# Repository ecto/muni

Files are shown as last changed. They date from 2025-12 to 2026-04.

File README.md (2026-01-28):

<picture>
  <source media="(prefers-color-scheme: dark)" srcset="web/public/images/muni-logo-dark.svg">
  <source media="(prefers-color-scheme: light)" srcset="web/public/images/muni-logo-light.svg">
  muni
</picture>

Open-source municipal robotics. Autonomous utility vehicles for public works, starting with sidewalk snow removal.

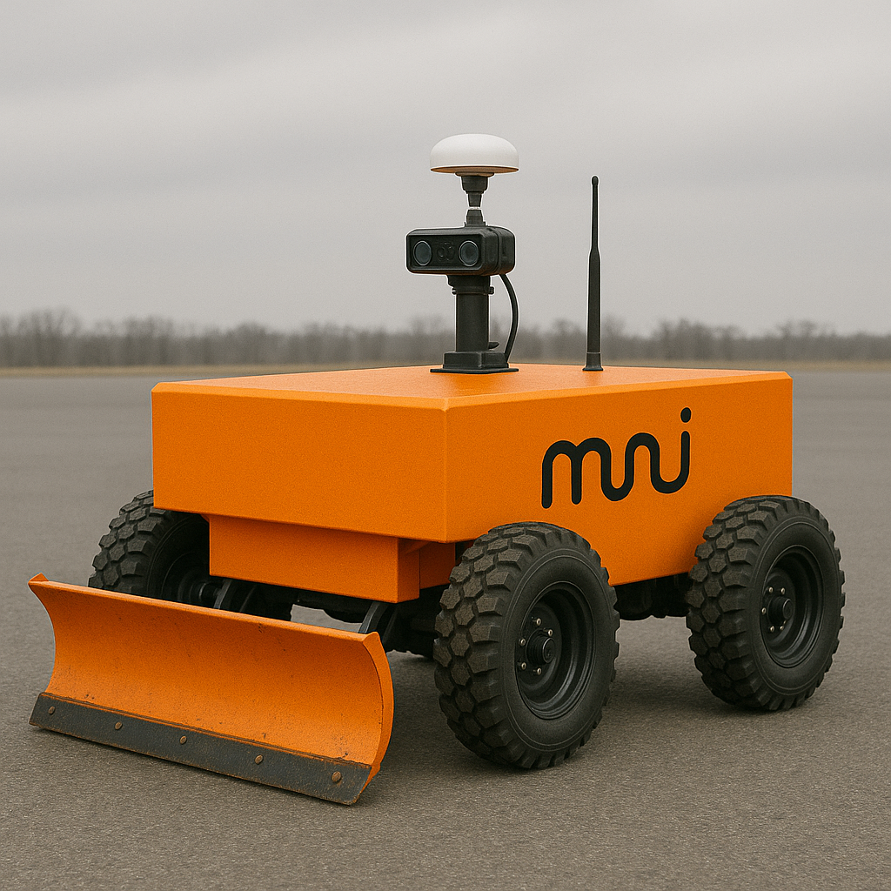
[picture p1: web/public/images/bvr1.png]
BVR rover with plow attachment


## Repository

```
muni/
├── bvr/              # Base Vectoring Rover (first morphology)
│   ├── firmware/     # Onboard software (Jetson Orin NX, Rust)
│   ├── cad/          # Mechanical design
│   ├── electrical/   # Schematics, PCBs
│   └── docs/         # BVR-specific documentation
├── depot/            # Base station (fleet ops, teleop, metrics)
├── mcu/              # Embedded firmware (RP2350, ESP32-S3)
├── paper/            # Technical documents (Typst)
└── web/              # Website
```

## Architecture

```
┌─────────────────────────────────────────────────────────────────────────────┐
│ Depot (Base Station)                                                        │
│                                                                             │
│   Console (:80)     Grafana (:3000)     InfluxDB        SFTP (:2222)       │
│   Fleet ops         Dashboards          Metrics DB      Session storage    │
│   Teleop UI         Alerts              Time series     Recording sync     │
└───────────────────────────────────┬─────────────────────────────────────────┘
                                    │
                        UDP metrics │ WebSocket teleop
                        SFTP sync   │ RTK corrections
                                    │
┌───────────────────────────────────┴─────────────────────────────────────────┐
│ BVR Rover                                                                   │
│                                                                             │
│   ┌─────────────────────────────────────────────────────────────────────┐  │
│   │ Jetson Orin NX                                                      │  │
│   │                                                                     │  │
│   │   bvrd (main daemon)                                                │  │
│   │   ├── teleop     Commands, telemetry, video streaming              │  │
│   │   ├── control    Differential drive mixer, rate limiting           │  │
│   │   ├── state      Mode management, safety interlocks                │  │
│   │   ├── gps        RTK positioning                                   │  │
│   │   └── recording  Session capture to .rrd files                     │  │
│   └───────────────────────────────┬─────────────────────────────────────┘  │
│                                   │ CAN bus                                 │
│       ┌───────────┬───────────────┼───────────────┬───────────────┐        │
│       │           │               │               │               │        │
│   ┌───┴───┐   ┌───┴───┐       ┌───┴───┐       ┌───┴───┐       ┌───┴───┐   │
│   │ VESC  │   │ VESC  │       │ VESC  │       │ VESC  │       │  MCU  │   │
│   │  FL   │   │  FR   │       │  RL   │       │  RR   │       │ LEDs  │   │
│   └───────┘   └───────┘       └───────┘       └───────┘       └───────┘   │
└─────────────────────────────────────────────────────────────────────────────┘
```

## Quick Start

### Base Station

```bash
cd depot
docker compose up -d
```

Console at http://localhost. See [depot/README.md](depot/README.md).

### BVR Firmware

```bash
cargo install --path bvr/firmware/bins/cli
muni deploy rover <rover-hostname>
```

See [bvr/firmware/README.md](bvr/firmware/README.md).

### MCU Firmware

```bash
cd mcu
cargo build --release -p mcu-rp2350
picotool load target/thumbv8m.main-none-eabihf/release/mcu-rp2350 -t elf -f
```

See [mcu/README.md](mcu/README.md).

## Documentation

| Topic | Link |
| --- | --- |
| System architecture | [bvr/docs/architecture.md](bvr/docs/architecture.md) |
| Hardware BOM | [docs/hardware/bom.md](docs/hardware/bom.md) |
| RTK GPS setup | [docs/hardware/rtk.md](docs/hardware/rtk.md) |
| Teleop system | [bvr/docs/teleop.md](bvr/docs/teleop.md) |
| Design language | [docs/design-language.md](docs/design-language.md) |

## License

MIT

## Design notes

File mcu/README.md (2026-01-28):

# MCU Firmware

Embedded firmware for CAN-connected microcontrollers on the rover.

## Architecture

```
mcu/
├── crates/
│   ├── mcu-core/          # Shared: CAN protocol, watchdog, heartbeat
│   └── mcu-leds/          # Driver: LED animations and control
└── bins/
    ├── rp2350/            # Binary: Base rover LED controller (Pico 2 W)
    └── esp32s3/           # Binary: Attachment controller (ESP32-S3)
```

## Hardware

### LED Controller (mcu-rp2350)

- **MCU**: Raspberry Pi Pico 2 W (RP2350)
- **LEDs**: WS2811 12V addressable strip (ALITOVE RGB, 4 addressable units)
- **CAN**: MCP2515 via SPI (planned)

#### Pinout

| Pico 2 Pin | Function |
| --- | --- |
| GP0 | LED data out |
| GP16 | MCP2515 MISO (TBD) |
| GP17 | MCP2515 CS (TBD) |
| GP18 | MCP2515 SCK (TBD)  |
| GP19 | MCP2515 MOSI (TBD) |
| GP20 | MCP2515 INT (TBD)  |

#### LED Wiring (WS2811 12V Strip)

```
LED Strip          Pico 2 W
─────────          ────────
+12V (red)    -->  External 12V supply
GND (white)   -->  GND (shared with 12V supply)
DIN (green)   -->  GP0 (data output)
```

**Important**: The data wire (green) must connect to the **input** end of the strip (marked with arrow or "DIN"). Data flows in one direction only.

### Attachment Controller (mcu-esp32s3)

- **MCU**: Heltec WiFi LoRa 32 V3 (ESP32-S3FN8)
- **Display**: Onboard 0.96" 128x64 OLED (SSD1306, I2C)
- **CAN**: ESP32-S3 native TWAI controller (no external chip needed)

This is a generic attachment controller for CAN-connected tool attachments. The OLED display shows status, CAN statistics, and debug info.

#### Pinout (Heltec V3)

| GPIO | Function | Notes |
| ---- | --- | --- |
| 17 | OLED SDA | I2C data (fixed) |
| 18 | OLED SCL | I2C clock (fixed) |
| 21 | OLED RST | Display reset (fixed) |
| 36 | Vext | OLED/peripheral power ctrl  |
| 35 | LED | Onboard status LED |
| 0 | PRG Button | Boot/user button |
| 4 | TWAI RX | CAN receive (configurable)  |
| 5 | TWAI TX | CAN transmit (configurable) |

#### Features

- `oled` (default): Enable OLED display support

#### CAN Wiring

Connect a CAN transceiver (e.g., SN65HVD230 or MCP2551) to GPIO4 (RX) and GPIO5 (TX):

```
ESP32-S3         CAN Transceiver       CAN Bus
────────         ───────────────       ───────
GPIO4 (RX)  <--  RXD
GPIO5 (TX)  -->  TXD
3.3V        -->  VCC
GND         -->  GND
                 CANH            <-->  CAN_H
                 CANL            <-->  CAN_L
```

## CAN Protocol

### ID Ranges

| Range | Purpose |
| --- | --- |
| 0x0A00-0x0AFF | Tool attachments (uses discovery) |
| 0x0B00-0x0BFF | Base rover peripherals (fixed assignment) |

### LED Controller (0x0B00-0x0B01)

**Command (0x0B00, Jetson -> MCU):**

```
[0]: Mode (0x00=Off, 0x01=Solid, 0x02=Pulse, 0x03=Chase, 0x04=Flash, 0x10=StateLinked)
[1]: Red (0-255)
[2]: Green (0-255)
[3]: Blue (0-255)
[4]: Brightness (0-255)
[5-6]: Period (ms, little-endian, for animations)
[7]: Reserved
```

**Status (0x0B01, MCU -> Jetson):**

```
[0]: Status (0x00=OK, 0x01=Fault)
[1]: Uptime seconds (wraps at 255)
[2-7]: Reserved
```

## Building

### Prerequisites

```bash
# Install Rust target for RP2350
rustup target add thumbv8m.main-none-eabihf

# Install picotool (for flashing)
brew install picotool  # macOS
# or build from https://github.com/raspberrypi/picotool
```

### Build

```bash
cd mcu
cargo build --release -p mcu-rp2350
```

### Flash

1. **Enter BOOTSEL mode**: Hold BOOTSEL button while plugging in USB
2. **Flash with picotool**:

```bash
picotool load target/thumbv8m.main-none-eabihf/release/mcu-rp2350 -t elf -f
picotool reboot
```

**Note**: Do NOT use `elf2uf2-rs` for RP2350 - it generates the wrong UF2 family ID (RP2040 instead of RP2350). Use `picotool` which correctly identifies the target.

## Debugging

Uses `defmt` for logging. With a debug probe (Picoprobe, etc.):

```bash
probe-rs run --chip RP235x target/thumbv8m.main-none-eabihf/release/mcu-rp2350
```

Without a debug probe, add USB serial logging (see embassy-usb-logger).

## RP2350 / Pico 2 W Notes

### Key Differences from RP2040

1. **Different UF2 family ID**: RP2350 uses `rp2350-arm-s` (0xe48bff59), not RP2040's 0xe48bff56
2. **Boot2 required**: Must enable `boot2-w25q080` feature in embassy-rp for the flash bootloader
3. **Memory layout**: Requires special linker sections for boot blocks (`.start_block`, `.end_block`)
4. **Onboard LED**: On Pico 2 W, the LED is controlled via CYW43 WiFi chip (not GPIO25)

### Required Embassy Features

```toml
embassy-rp = { version = "0.9", features = [
    "rp235xa",              # RP2350 variant
    "time-driver",          # Async timers
    "boot2-w25q080",        # Flash bootloader (REQUIRED)
    "critical-section-impl", # Critical section implementation
    "binary-info",          # Picotool metadata
] }
```

### Required Linker Script Sections

The `memory.x` must include boot block sections for RP2350:

```ld
SECTIONS {
    .start_block : ALIGN(4) {
        __start_block_addr = .;
        KEEP(*(.start_block));
        KEEP(*(.boot_info));
    } > FLASH
} INSERT AFTER .vector_table;

_stext = ADDR(.start_block) + SIZEOF(.start_block);

SECTIONS {
    .bi_entries : ALIGN(4) {
        __bi_entries_start = .;
        KEEP(*(.bi_entries));
        . = ALIGN(4);
        __bi_entries_end = .;
    } > FLASH
} INSERT AFTER .text;

SECTIONS {
    .end_block : ALIGN(4) {
        __end_block_addr = .;
        KEEP(*(.end_block));
    } > FLASH
} INSERT AFTER .uninit;
```

### Build.rs Requirements

```rust
// Required linker args for RP2350
println!("cargo:rustc-link-arg-bins=--nmagic");
println!("cargo:rustc-link-arg-bins=-Tlink.x");
println!("cargo:rustc-link-arg-bins=-Tdefmt.x");
```

### Troubleshooting

**Firmware doesn't run after flashing:**

- Verify UF2 family ID is `rp2350-arm-s` (check with `xxd file.uf2 | head`)
- Use `picotool` instead of `elf2uf2-rs`
- Check `picotool info -a` for boot diagnostics

**Picotool shows "Program Information: none":**

- Device is in BOOTSEL mode, not running application
- Check that boot2 feature is enabled
- Verify memory.x has correct boot block sections

**LEDs not working:**

- Verify data wire goes to DIN (input) end of strip
- Check WS2811 vs WS2812 timing (WS2811 uses 400kHz, WS2812 uses 800kHz)
- Try different color order (GRB vs RGB) - use `Grb` type in PioWs2812
- Confirm LED count matches addressable units (WS2811 12V has 3 LEDs per IC)

## LED Modes

| Mode  | Color  | Effect | Use Case |
| ----- | --- | --- | --- |
| Off | - | - | Disabled |
| Solid | Green  | Constant | Idle |
| Pulse | Blue | Breathing | Teleop active |
| Pulse | Cyan | Breathing | Autonomous |
| Flash | Red | Strobe 200ms | E-Stop |
| Flash | Orange | Strobe 500ms | Fault |

## ESP32-S3 / Heltec LoRa 32 V3 Notes

### Prerequisites

```bash
# Install espup (ESP32 Rust toolchain manager)
cargo install espup
espup install

# Source the environment (add to shell profile for persistence)
source ~/export-esp.sh

# Install espflash for flashing
cargo install espflash
```

### Build

```bash
cd mcu/bins/esp32s3
cargo build --release
```

### Flash

```bash
# Flash and open serial monitor
espflash flash --monitor target/xtensa-esp32s3-none-elf/release/mcu-esp32s3

# Or just flash
espflash flash target/xtensa-esp32s3-none-elf/release/mcu-esp32s3
```

The board will automatically reset and start running after flashing.

### Debugging

Serial output uses `defmt` via `esp-println`. The `--monitor` flag with espflash shows logs:

```bash
espflash flash --monitor target/xtensa-esp32s3-none-elf/release/mcu-esp32s3
```

### Troubleshooting

**"Permission denied" on /dev/ttyUSB0 or /dev/ttyACM0:**

```bash
sudo usermod -a -G dialout $USER
# Log out and back in
```

**OLED not displaying:**

- Check Vext is enabled (GPIO36 low)
- Verify OLED reset sequence (GPIO21 low then high)
- Confirm I2C address is 0x3C

**CAN not working:**

- Verify CAN transceiver is connected and powered
- Check termination resistors (120Ω at each end of bus)
- Confirm baud rate matches other nodes (500kbps default)

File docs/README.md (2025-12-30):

# Muni Platform Documentation

Platform-level documentation for the Muni robotics system.

## Contents

- Fleet management and deployment
- Depot configuration and operations
- Cross-morphology standards

## Hardware

- [Bill of Materials](hardware/bom.md) — Complete parts list and costs
- [Depot Rack](hardware/depot.md) — Base station 10" rack setup
- [Rover Rack](hardware/rover-rack.md) — Rover electronics enclosure
- [RTK GPS](hardware/rtk.md) — Centimeter-accurate positioning
- [Motors](hardware/motors.md) — Hub motor specifications
- [Networking](hardware/networking.md) — LTE and local connectivity
- [Firmware](hardware/firmware.md) — Flashing bvrd and attachments

## Morphology-Specific Docs

For hardware and firmware documentation specific to each robot type, see:

- [BVR Documentation](../bvr/docs/) — Base Vectoring Rover

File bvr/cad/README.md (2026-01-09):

# BVR CAD

Parametric CAD system for BVR rover parts, written in Rust using [manifold-rs](https://github.com/WilstonOreo/manifold-rs).

## Structure

```
cad/
├── src/
│   ├── lib.rs          # Core Part abstraction
│   ├── step.rs         # STEP export (optional, requires OpenCASCADE)
│   ├── parts/          # Part definitions
│   │   ├── motor_mount.rs      # Custom: L-bracket motor mounts
│   │   ├── electronics_plate.rs # Custom: Electronics mounting plate
│   │   ├── sensor_mount.rs     # Custom: Sensor mast bracket
│   │   ├── wheel_spacer.rs     # Custom: Wheel spacers
│   │   ├── frame.rs            # Frame: 2020 extrusion, brackets
│   │   ├── hub_motor.rs        # Reference: Hub motors
│   │   ├── sensors.rs          # Reference: LiDAR, cameras, GPS
│   │   ├── electronics.rs      # Reference: VESCs, Jetson, DC-DC
│   │   ├── battery.rs          # Reference: Battery packs
│   │   └── assembly.rs         # Complete BVR1 assembly
│   └── bin/
│       └── generate_all.rs
├── exports/            # Generated STL files (29 parts)
└── viewer.html         # 3D viewer (Three.js)
```

## Quick Start

```bash
# Build the CAD library
cargo build

# Generate all parts (31 STL files)
cargo run --bin generate-all

# Run tests (51 tests)
cargo test

# View parts in browser
open viewer.html
```

## Part Categories

### Custom Fabricated Parts

These are parts designed for manufacturing (3D printing, laser cutting):

| Part | Description | File |
|---|---|---|
| Motor Mount | L-bracket for hub motors | `motor_mount_8in.stl` |
| Electronics Plate | Jetson + 4x VESC mounting | `electronics_plate.stl` |
| Sensor Mount | 1" tube clamp for mast | `sensor_mount.stl` |
| Wheel Spacer | Hub motor axle spacer | `wheel_spacer_8in.stl` |
| Battery Tray | Custom battery enclosure | `battery_tray.stl` |

### Reference Parts (Visualization)

Simplified models of off-the-shelf components for assembly visualization:

| Part | Description | File |
|---|---|---|
| Hub Motor 8" | 48V hub motor with wheel | `ref_hub_motor_8in.stl` |
| Hoverboard Motor | 6.5" BVR0-style motor | `ref_hub_motor_hoverboard.stl` |
| LiDAR Mid-360 | Livox Mid-360 sensor | `ref_lidar_mid360.stl` |
| Camera | Insta360 X4 | `ref_camera_insta360.stl` |
| GPS Antenna | RTK antenna | `ref_gps_antenna.stl` |
| VESC 6 | Motor controller | `ref_vesc_6.stl` |
| Jetson | reComputer carrier | `ref_jetson_recomputer.stl` |
| DC-DC | 48V to 12V converter | `ref_dcdc.stl` |
| E-Stop | Mushroom button | `ref_estop.stl` |
| Downtube Battery | BVR0 e-bike battery | `ref_battery_downtube.stl` |
| Custom Battery | BVR1 13S4P pack | `ref_battery_custom.stl` |

### Frame Components

2020 aluminum extrusion system:

| Part | Description | File |
|---|---|---|
| 2020 Extrusion | Standard profiles | `extrusion_2020_*.stl` |
| Corner Bracket | 90° joining bracket | `corner_bracket.stl` |
| T-Nut | M5 sliding nut | `tnut_m5.stl` |
| BVR1 Frame | Complete chassis | `bvr1_frame.stl` |

### Complete Assemblies

| Assembly | Description | File |
|---|---|---|
| BVR0 Full | Prototype with hoverboard motors, downtube battery | `bvr0_assembly.stl` |
| BVR0 Simple | Simplified BVR0 for fast rendering | `bvr0_assembly_simple.stl` |
| BVR1 Full | Production with 8" motors, custom battery | `bvr1_assembly.stl` |
| BVR1 Simple | Simplified BVR1 for fast rendering | `bvr1_assembly_simple.stl` |

## Usage Examples

### Frame

```rust
use bvr_cad::parts::{Extrusion2020, CornerBracket, BVR1Frame};

// Single extrusion
let rail = Extrusion2020::new(500.0).generate();
rail.write_stl("rail.stl")?;

// Complete BVR1 frame assembly
let frame = BVR1Frame::default_bvr1().generate();
frame.write_stl("bvr1_frame.stl")?;
```

### Motor Mount

```rust
use bvr_cad::parts::MotorMount;

let mount = MotorMount::hub_motor_8in();
mount.generate().write_stl("motor_mount.stl")?;
mount.generate_flat_plate().write_stl("plate.stl")?; // For laser cutting
```

### Complete Assembly

```rust
use bvr_cad::parts::{BVR0Assembly, BVR1Assembly};

// BVR0: Prototype with hoverboard motors, downtube battery
let bvr0 = BVR0Assembly::default_bvr0();
bvr0.generate().write_stl("bvr0_complete.stl")?;

// BVR1: Production with 8" motors, custom battery
let bvr1 = BVR1Assembly::default_bvr1();
bvr1.generate().write_stl("bvr1_complete.stl")?;
```

### Custom Primitives

```rust
use bvr_cad::{Part, centered_cube, centered_cylinder, bolt_pattern};

// Primitives
let plate = centered_cube("plate", 100.0, 100.0, 6.0);
let hole = centered_cylinder("hole", 5.0, 10.0, 32);

// Boolean operations
let result = plate.difference(&hole);

// Transformations
let moved = result.translate(10.0, 0.0, 0.0);
let rotated = moved.rotate(0.0, 0.0, 45.0);

// Export
result.write_stl("output.stl")?;
```

## Manufacturing

### Laser Cutting (SendCutSend)
- Use `generate_flat_plate()` methods for 2D profiles
- Export STL, convert to DXF using FreeCAD/Blender

### 3D Printing
- Use `generate()` for full 3D parts
- STL files ready for slicing

### STEP Export (for Shapr3D, Fusion 360)
Requires OpenCASCADE (optional feature):

```bash
# Install dependencies
brew install cmake opencascade  # macOS
sudo apt install cmake libocct-dev  # Ubuntu

# Build with STEP support
cargo build --features step
```

## Dependencies

- `manifold-rs` - CSG geometry kernel (requires cmake, ninja)
- `nalgebra` - Linear algebra
- `opencascade` (optional) - STEP export (requires OCCT)

## Build Requirements

```bash
# macOS
brew install cmake ninja

# Ubuntu/Debian
sudo apt install cmake ninja-build build-essential
```

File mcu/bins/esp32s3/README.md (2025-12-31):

# ESP32-S3 MCU Firmware

Generic attachment controller firmware for ESP32-S3 based boards (Heltec LoRa 32 V3, etc.).

## Features

- **OLED Display**: 128x64 SSD1306 with animated UI
  - Splash screen with Muni branding
  - Status indicator with pulsing animation
  - State display (IDLE, RUNNING, ERROR)
  - Cycling info bar (activity, CAN health, device info)
- **Dual Protocol Serial Interface**:
  - Text commands for debugging
  - SLCAN (CAN-over-serial) for bvrd integration
- **Status LEDs** (feature: `status-bar`):
  - 5 GPIO LEDs: Red (error), Yellow (warn), Green (idle), Blue (running), White (heartbeat)
  - Configurable patterns per state
- **Addressable LED Driver** (feature: `addressable-leds`):
  - RMT-based for precise timing
  - WS2811 (400kHz) and WS2812/SK6812 (800kHz) support
  - RGB/GRB/BGR color order options
  - RGB cycle mode for testing

## Supported Hardware

- **Heltec WiFi LoRa 32 V3 / V3.2** (ESP32-S3FN8)
- Other ESP32-S3 boards with minor pin adjustments

### Heltec V3 Pinout

| GPIO | Function | Notes |
| ---- | --- | --- |
| 17 | OLED SDA | I2C data |
| 18 | OLED SCL | I2C clock |
| 21 | OLED RST | Display reset |
| 36 | Vext | OLED power control (LOW = on) |
| 35 | LED | Onboard status LED |
| 0 | PRG Button | Boot/user button |
| 4 | LED Strip Data | WS2811/WS2812 (needs level shifter for 12V strips) |
| 43 | UART TX | Serial output (CP2102) |
| 44 | UART RX | Serial input (CP2102) |

### Status Bar LEDs (feature: `status-bar`)

| GPIO | Color  | Meaning |
| ---- | --- | --- |
| 19 | Red | Error/fault |
| 20 | Yellow | Warning/attention |
| 26 | Green  | Idle/ok |
| 48 | Blue | Running/active |
| 47 | White  | Heartbeat |

Wire each LED: `GPIO → 330Ω resistor → LED anode (+) → LED cathode (-) → GND`

## Communication Protocols

The firmware supports two protocols over USB serial:

### 1. Text Commands (Human/Debug)

Connect via screen or any serial terminal at 115200 baud:

```bash
screen /dev/cu.usbserial-0001 115200
```

| Command | Description |
| --- | --- |
| `led r,g,b` | Set LED color (0-255 each) |
| `led off` | Turn off LEDs |
| `cycle` | Toggle RGB rainbow cycle mode  |
| `state idle` | Set display state to IDLE |
| `state running` | Set display state to RUNNING |
| `state error` | Set display state to ERROR |
| `rgb/grb/bgr` | Set LED color order |
| `ws2811/ws2812` | Set LED timing (400kHz/800kHz) |
| `help` | Show available commands |

Exit screen with `Ctrl+A` then `K` then `Y`.

### 2. SLCAN (CAN-over-Serial for bvrd)

The firmware implements SLCAN protocol for integration with bvrd. This allows unified CAN messaging whether using USB serial or hardware CAN.

**SLCAN Commands:**

| Command | Description |
| --- | --- |
| `O` | Open CAN channel (starts heartbeat) |
| `C` | Close CAN channel |
| `tIIILDD...` | Send standard frame (11-bit ID) |
| `TIIIIIIIILDD...` | Send extended frame (29-bit ID) |
| `V` | Query firmware version |
| `N` | Query serial number |

**Example:**

```bash
# Open channel
echo -ne "O\r" > /dev/ttyUSB0

# Query identity (ID 0x201, 0 data bytes)
echo -ne "t2010\r" > /dev/ttyUSB0

# Set LED to red (ID 0x203, cmd=0x10, r=255, g=0, b=0)
echo -ne "t20341000FF00\r" > /dev/ttyUSB0
```

## CAN Protocol (Message IDs)

Attachments use CAN IDs in the `0x200-0x2FF` range. Each attachment slot gets 16 IDs.

### Attachment Slot 0 (Base ID 0x200)

| ID | Dir | Name | Description |
| ----- | --- | --- | --- |
| 0x200 | A→H | Heartbeat | Periodic status (1Hz when channel open) |
| 0x201 | H→A | Identify  | Request attachment info |
| 0x202 | A→H | Identity  | Response with type/version/caps |
| 0x203 | H→A | Command | Control command |
| 0x204 | A→H | Ack | Command acknowledgment |
| 0x205 | A→H | Sensor | Sensor data broadcast |
| 0x206 | H→A | Config | Configuration update |
| 0x207 | A→H | Error | Error/fault report |

A = Attachment, H = Host (bvrd/Jetson)

### Heartbeat Frame (0x200)

Sent every ~1 second when SLCAN channel is open:

```
Byte 0: State (0=Idle, 1=Running, 2=Error, 3=Warning)
Byte 1: Uptime (seconds, low byte)
Byte 2: Uptime (seconds, high byte)
Byte 3: Flags (reserved)
```

### Identity Frame (0x202)

Response to Identify request:

```
Byte 0: Attachment type (0x02 = LedStrip)
Byte 1: Hardware revision
Byte 2: Software version major
Byte 3: Software version minor
Byte 4: Capabilities (0x01=LED, 0x02=Sensor, 0x04=Actuator)
```

### Command Frame (0x203)

| Cmd  | Name | Args |
| ---- | --- | --- |
| 0x00 | Nop | (none) |
| 0x01 | Enable | (none) |
| 0x02 | Disable | (none) |
| 0x03 | SetState  | arg0=state |
| 0x10 | SetLed | arg0=R, arg1=G, arg2=B |
| 0x11 | LedCycle  | arg0=0/1 (off/on) |
| 0x12 | LedTiming | arg0=0/1 (SK68/WS2811) |
| 0x13 | LedOrder  | arg0=0/1/2 (RGB/GRB/BGR) |

### Ack Frame (0x204)

```
Byte 0: Command that was acknowledged
Byte 1: Result (0x00=Ok, 0x01=UnknownCmd, 0x02=InvalidArgs)
```

## Full-Stack Integration

```
┌─────────────┐     WebSocket      ┌─────────────┐
│  Operator   │◄──────────────────►│   Depot     │
│    App      │                    │  (Cloud)    │
└─────────────┘                    └─────────────┘
                                          ▲
                                          │ gRPC/HTTP
                                          ▼
                                   ┌─────────────┐
                                   │    bvrd     │
                                   │  (Jetson)   │
                                   └─────────────┘
                                          ▲
                                          │ USB Serial (SLCAN)
                                          ▼
                                   ┌─────────────┐
                                   │ Attachment  │
                                   │   (ESP32)   │
                                   └─────────────┘
```

1. **Discovery**: bvrd detects USB device, sends `O` then `t2010` (Identify)
2. **Registration**: Attachment responds with Identity frame (0x202)
3. **Heartbeat**: Attachment sends periodic heartbeat (0x200)
4. **Control**: Operator sends command through Depot → bvrd → SLCAN → Attachment
5. **Status**: Attachment heartbeat flows back to Operator via Depot

## Prerequisites

```bash
# Install ESP32 Rust toolchain
cargo install espup
espup install

# Add to your shell profile (~/.zshrc or ~/.bashrc)
source ~/export-esp.sh

# Install espflash
cargo install espflash
```

## Building

```bash
cd mcu/bins/esp32s3
source ~/export-esp.sh
cargo build --release
```

## Flashing

**Important**: Use the included `bootloader.bin` to avoid chip revision compatibility issues.

```bash
espflash flash \
    --ignore-app-descriptor \
    --partition-table partitions.csv \
    --bootloader bootloader.bin \
    --min-chip-rev 0.0 \
    target/xtensa-esp32s3-none-elf/release/mcu-esp32s3
```

To monitor serial output:

```bash
espflash monitor
```

Press `CTRL+R` to reset, `CTRL+C` to exit.

## WS2811 LED Strip Setup

The ESP32 outputs 3.3V logic, but 12V WS2811 strips require 5V logic levels.

### Required Hardware

**Level Shifter**: Use a bidirectional logic level converter (3.3V to 5V):

- 4-channel I2C Logic Level Converter module (recommended)
- 74HCT125
- SN74AHCT125N
- TXB0104

### Wiring with Level Shifter

```
ESP32 (3.3V side)          Level Shifter          LED Strip (5V side)
─────────────────          ─────────────          ──────────────────
3.3V  ──────────────────── LV
GND   ──────────────────── GND ─────────────────── GND
GPIO4 ──────────────────── LV1 ──── HV1 ────────── DIN
                           HV ──────────────────── 5V (from LED power)
```

| From | To |
| --- | --- |
| ESP32 3.3V | LV pin |
| ESP32 GND | GND pin (either side) |
| ESP32 GPIO4 | LV1 |
| 5V power supply | HV pin |
| HV1 | LED strip DIN |

### Why Level Shifting is Required

- WS2811 data input threshold: ~0.7 \* VDD = 3.5V (for 5V power)
- ESP32 GPIO output: 3.3V
- 3.3V < 3.5V = unreliable detection

Without a level shifter, only the first LED may respond, and colors will be incorrect.

## Critical Configuration

### .cargo/config.toml

The linker script is **required** for proper linking:

```toml
[target.xtensa-esp32s3-none-elf]
runner = "espflash flash --monitor"
rustflags = [
  "-C", "link-arg=-Wl,-Tlinkall.x",  # REQUIRED: Links esp-hal runtime
  "-C", "link-arg=-nostartfiles",
]

[build]
target = "xtensa-esp32s3-none-elf"

[unstable]
build-std = ["alloc", "core"]
```

Without `-Tlinkall.x`, the binary will have entry point 0x0 and fail to boot.

### Bootloader Compatibility

ESP-IDF v5.5.x bootloaders have a strict "efuse block revision" check that fails on ESP32-S3 v0.2 chips. The error looks like:

```
E (95) boot_comm: Image requires efuse blk rev >= v20.50, but chip is v1.3
E (101) boot: Factory app partition is not bootable
```

**Solution**: Use the included `bootloader.bin` (ESP-IDF v5.1-beta1) which doesn't have this check.

To update the bootloader:

```bash
curl -sL "https://github.com/esp-rs/espflash/raw/v3.0.0/espflash/resources/bootloaders/esp32s3-bootloader.bin" -o bootloader.bin
```

## Entering Bootloader Mode

If the board is stuck or unresponsive:

1. **Unplug USB**
2. **Hold BOOT/PRG button**
3. **Plug in USB** (keep holding)
4. **Release after 2 seconds**

This forces download mode for flashing.

## Troubleshooting

### Binary is empty / entry point 0x0

- Check `.cargo/config.toml` has `-Wl,-Tlinkall.x`
- Verify `build-std = ["alloc", "core"]`
- Clean rebuild: `cargo clean && cargo build --release`

Verify with:

```bash
xtensa-esp32s3-elf-readelf -h target/xtensa-esp32s3-none-elf/release/mcu-esp32s3
# Entry point should be ~0x40378xxx, not 0x0
```

### "abort() was called" on boot

- Usually caused by missing linker script
- Check entry point as above

### "efuse blk rev" error

- Use older bootloader: `--bootloader bootloader.bin`
- ESP-IDF v5.5.x has incompatible checks for v0.2 chips

### OLED not displaying

- Vext must be LOW (GPIO36) to power display
- Reset sequence: GPIO21 LOW -> 50ms -> HIGH -> 50ms
- I2C address: 0x3C (some boards use 0x3D)
- Pins: SDA=GPIO17, SCL=GPIO18

### UART read blocking main loop

- Use `embedded_io::ReadReady` trait to check for data before reading
- `uart.read()` is blocking; always check `read_ready()` first

### Serial port not found

```bash
# Check if another process is using it
lsof /dev/cu.usbserial-*

# Kill conflicting processes
killall screen
```

### Permission denied (Linux)

```bash
sudo usermod -a -G dialout $USER
# Log out and back in
```

### LEDs not responding (WS2811)

- **Level shifter required**: 3.3V GPIO cannot reliably drive 5V WS2811
- Check wiring: GND must be shared between ESP32 and LED power supply
- Verify data pin is connected to strip INPUT (marked DIN or with arrow)
- Try different GPIO if issues persist

## Files

| File | Purpose |
| --- | --- |
| `bootloader.bin` | ESP-IDF v5.1-beta1 bootloader (compatible) |
| `partitions.csv` | Partition table (nvs, phy_init, factory) |
| `.cargo/config.toml`  | Cargo build configuration with linker args |
| `rust-toolchain.toml` | ESP Rust toolchain specification |

## Lessons Learned

1. **Linker script is mandatory**: Without `-Wl,-Tlinkall.x`, the esp-hal runtime isn't linked and the binary is empty.

2. **Bootloader version matters**: ESP-IDF v5.5.x introduced strict efuse block revision checks that reject valid binaries on older ESP32-S3 chips (v0.2).

3. **Vext controls OLED power**: The Heltec boards use GPIO36 (active low) to control power to the OLED and other peripherals. Must be set LOW before display works.

4. **OLED reset sequence is required**: GPIO21 must be toggled (low -> high) with delays for the SSD1306 to initialize properly.

5. **Use `core::mem::forget` for GPIO pins**: If GPIO pins go out of scope, they're reconfigured. Use `forget()` to keep them alive.

6. **UART read is blocking**: The `embedded_io::Read` trait's `read()` method blocks. Use `ReadReady::read_ready()` first to avoid blocking the main loop.

7. **WS2811 vs WS2812 timing**: WS2811 (often 12V strips) uses 400kHz timing, WS2812 (5V strips) uses 800kHz. The timing is completely different.

8. **Level shifting for LED strips**: 12V WS2811 strips need 5V logic. ESP32's 3.3V output is below the detection threshold. A bidirectional level shifter is required.

9. **heapless collections can panic**: Using `.collect()` on iterators with `heapless::Vec` will panic if the iterator has more elements than the Vec capacity. Use manual iteration instead.

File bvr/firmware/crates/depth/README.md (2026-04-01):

# depth — Camera-Based Perception

Monocular depth estimation, 3D back-projection, and visual odometry for
BVR rovers using commodity USB cameras instead of lidar.

## Architecture

```
3× Arducam IMX291 (120° FOV, USB 2.0)
        │
        ▼ raw RGB (640×480 @ 15fps)
┌─────────────────────────────────────────────────┐
│  depth crate                                    │
│                                                 │
│  1. DepthEstimator (ONNX)                       │
│     RGB → relative depth map (518×518)          │
│     Depth Anything V2/V3 Small, TensorRT on     │
│     Jetson Orin NX                              │
│                                                 │
│  2. estimate_metric_scale()                     │
│     Relative depth → metric depth using known   │
│     camera mount height as reference            │
│                                                 │
│  3. backproject_and_classify()                  │
│     Depth pixels → 3D points in rover frame     │
│     Classified as ground or obstacle by height  │
│                                                 │
│  4. VisualOdometry (2D ICP)                     │
│     Frame-to-frame ego-motion from ground-plane │
│     point alignment. Returns (dx, dy, dθ)       │
│     compatible with EKF prediction.             │
└──────────┬──────────────────────┬───────────────┘
           │                      │
           ▼                      ▼
     Costmap update         EKF prediction
     (obstacles →           (replaces wheel
      navigation)            odometry)
```

## Coordinate Frames

**Camera frame** (OpenCV): Z-forward, X-right, Y-down
**Rover frame** (ROS): X-forward, Y-left, Z-up

Base rotation (camera → rover, no mount):
```
rover_X =  cam_Z    (forward = depth)
rover_Y = -cam_X    (left = -right)
rover_Z = -cam_Y    (up = -down)
```

**Mount rotation convention**: `[roll, pitch, yaw]` Euler angles (intrinsic
ZYX via `nalgebra::from_euler_angles`) describing the rotation FROM rover
frame TO camera frame. Negative pitch = looking down.

Transform to rover frame: `R_mount.transpose() * R_cam_to_rover_base * p_cam + translation`

## Camera Mount Configuration

```toml
# config/bvr.toml — 3× cameras at 120° apart for ~360° coverage

[[camera.mounts]]
id = "left"
device_hint = "/dev/video0"
mount_position = [0.25, 0.12, 0.25]      # [forward, left, up] meters
mount_rotation = [0.0, -0.175, -2.094]    # [roll, pitch, yaw] radians
fov_h = 1.745   # ~100° horizontal
fov_v = 1.18    # ~68° vertical

[[camera.mounts]]
id = "center"
device_hint = "/dev/video2"
mount_position = [0.25, 0.0, 0.25]
mount_rotation = [0.0, -0.175, 0.0]       # forward-facing

[[camera.mounts]]
id = "right"
device_hint = "/dev/video4"
mount_position = [0.25, -0.12, 0.25]
mount_rotation = [0.0, -0.175, 2.094]     # yaw +120°
```

## Depth Perception Configuration

```toml
[depth]
enabled = true
model_path = "/var/lib/bvr/models/depth-anything-v2-small.onnx"
model_input_width = 518
model_input_height = 518
capture_width = 640
capture_height = 480
capture_fps = 15
max_depth = 8.0
min_depth = 0.3
ground_threshold = 0.10
stride = 4
visual_odometry = true
icp_max_dist = 0.5
icp_max_iterations = 20
```

## Visual Odometry

Ego-motion estimation from depth-derived 2D scans, using Iterative Closest
Point (ICP) with KD-tree nearest-neighbor search. Replaces wheel odometry
for platforms without encoders (chain drive).

1. Project all classified 3D points to 2D ground plane `(x, y)`
2. Build KD-tree from previous frame's points
3. Iteratively find correspondences and solve SVD-based rigid alignment
4. Return `(dx, dy, dθ)` — same interface as `WheelOdometry::update()`
5. Feed into `EkfPoseEstimator::predict()` alongside IMU gyro-Z

Sanity checks: rejects estimates exceeding `max_displacement` (0.5m) or
`max_rotation` (0.3 rad) per frame. Requires minimum 50 points.

## Feature Flags

- **default**: Core types, back-projection, visual odometry. No ML dependencies.
- **onnx**: Adds `DepthEstimator` (ONNX Runtime inference). Requires `ort` crate.
  On Jetson, automatically uses TensorRT execution provider.

```toml
# For development (no model inference)
depth = { path = "crates/depth" }

# For Jetson deployment (with TensorRT)
depth = { path = "crates/depth", features = ["onnx"] }
```

## Integration with bvrd

The depth pipeline is wired into `bins/bvrd/src/init.rs` and
`bins/bvrd/src/run_loop.rs`:

1. **init.rs**: Creates `CameraGeometry` per mount, spawns raw capture threads,
   initializes `VisualOdometry` and `DepthPerceptionConfig`
2. **run_loop.rs**: Each iteration drains latest raw frame per camera, runs
   depth estimation + back-projection, updates costmap, runs VO → EKF

The pipeline is gated on `[depth] enabled = true` in `bvr.toml`. When depth
is enabled alongside lidar, both feed into the same costmap.

## Model Setup

Download Depth Anything V2 Small ONNX:

```bash
# On the Jetson or dev machine
mkdir -p /var/lib/bvr/models
# Download from HuggingFace (Depth-Anything-V2-Small-hf)
# Export to ONNX with input shape [1, 3, 518, 518]
```

On first run with TensorRT EP, ONNX Runtime builds a TRT engine (takes
~2-5 minutes). Subsequent runs load the cached engine instantly.

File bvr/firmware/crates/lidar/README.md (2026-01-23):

# lidar

Livox Mid360 LiDAR driver for the BVR rover.

## Overview

This crate provides a Rust driver for the Livox Mid360 3D LiDAR sensor. It receives point cloud data over UDP using the Livox SDK2 protocol and produces 3D point clouds for SLAM, obstacle detection, and mapping.

## Features

- Async UDP receiver using Tokio
- 3D point cloud frames (~10k points per frame at 10Hz)
- Multiple point data formats (Cartesian 32-bit, 16-bit, Spherical)
- Optional IMU data streaming
- Frame assembly from multiple UDP packets

## Hardware Specifications

**Livox Mid360:**
- Range: 0.1m - 70m
- FOV: 360° × 59° (non-repetitive scanning)
- Point rate: 200,000 points/second
- Scan rate: ~10 Hz (full coverage)
- Interface: Ethernet (100BASE-TX)
- Power: PoE or 9-27V DC

## Network Configuration

The Mid360 uses fixed UDP ports:

| Data Type | LiDAR Port | Host Port |
|---|---|---|
| Point Cloud | 56300 | 56301 |
| IMU Data | 56400 | 56401 |
| Commands | 56100 | 56101 |

Default LiDAR IP: `192.168.1.1xx` (last two digits from serial number)

### Network Setup (BVR Rover)

The Mid360 uses the HAP (High-speed API Protocol) which broadcasts its configuration on startup. The LiDAR sends data to a pre-configured host IP that may differ from the rover's primary interface.

**Discovering the LiDAR:**
```bash
# Capture HAP broadcast packets to find the LiDAR
sudo tcpdump -i eth0 udp port 10001 -c 5

# Look for packets from 192.168.1.1xx containing DevType:Mid-360
# The packet also shows what host IP the LiDAR expects to send data to
```

**Adding a secondary IP (if LiDAR expects a different host):**
```bash
# Temporary (lost on reboot)
sudo ip addr add 192.168.1.5/24 dev eth0

# Permanent (NetworkManager)
sudo nmcli connection modify eth0 +ipv4.addresses '192.168.1.5/24'
sudo nmcli connection up eth0
```

**Verify data is flowing:**
```bash
# Should see UDP packets on port 56301 (point cloud) and 56401 (IMU)
sudo tcpdump -i eth0 host 192.168.1.177 -c 20
```

## Usage

```rust
use lidar::{Config, LidarReader, PointCloud};
use std::net::Ipv4Addr;
use tokio::sync::watch;

#[tokio::main]
async fn main() {
    let config = Config {
        lidar_ip: Ipv4Addr::new(192, 168, 1, 100),
        point_cloud_port: 56301,
        imu_port: 56401,
        ..Default::default()
    };

    let (tx, mut rx) = watch::channel(None);
    let reader = LidarReader::new(config);
    let _handle = reader.spawn(tx);

    // Process point clouds
    while rx.changed().await.is_ok() {
        if let Some(cloud) = &*rx.borrow() {
            println!("Frame {}: {} points", cloud.frame_id, cloud.points.len());
            for p in &cloud.points {
                println!("  ({:.2}, {:.2}, {:.2})", p.x, p.y, p.z);
            }
        }
    }
}
```

## Example

Run the interactive point cloud viewer:

```bash
# Default IP (192.168.1.100)
cargo run --example read_points

# Custom IP
cargo run --example read_points -- --ip 192.168.1.101
```

## PointCloud Format

Each `PointCloud` contains:
- `timestamp`: Local time when frame was received
- `timestamp_ns`: LiDAR nanosecond timestamp (GPS synced if available)
- `frame_id`: Monotonic frame counter
- `points`: Vector of `Point3D`:
  - `x`, `y`, `z`: Coordinates in meters (LiDAR frame)
  - `reflectivity`: Surface reflectivity (0-255)
  - `tag`: Classification flags

## Coordinate System

The Mid360 uses a right-handed coordinate system:
- X: Forward (along the connector direction)
- Y: Left
- Z: Up

## Configuration

In `bvr.toml`:

```toml
[lidar]
enabled = true
lidar_ip = "192.168.1.177"      # LiDAR IP (find via HAP broadcast)
host_ip = "192.168.1.5"         # Host IP the LiDAR sends data to
point_cloud_port = 56301
imu_port = 56401                # Set to 0 to disable IMU
mounting_pitch_deg = 30.0       # LiDAR tilt angle (positive = tilted down)
```

### Mounting Angle

The `mounting_pitch_deg` parameter compensates for the physical mounting angle of the LiDAR. When the LiDAR is tilted forward (pitched down), set this to a positive value. The driver applies a rotation to transform points from the LiDAR frame to the rover body frame.

For BVR rovers, the Mid360 is typically mounted at 30° pitch to provide better ground coverage for obstacle detection.

## Integration

Add to your `Cargo.toml`:

```toml
[dependencies]
lidar = { path = "../lidar" }
tokio = { version = "1", features = ["net", "sync", "rt"] }
```

Or use workspace dependencies:

```toml
[dependencies]
lidar.workspace = true
```

## Testing

```bash
# Run unit tests
cargo test -p lidar

# Build all targets
cargo check -p lidar --all-targets
```

## Related Crates

- `gps` - GPS receiver driver (similar watch channel pattern)
- `localization` - Sensor fusion for pose estimation
- `recording` - Rerun integration for data capture
- `slam` - SLAM processing using point clouds

## Protocol Reference

Based on [Livox Mid360 Ethernet Protocol](https://livox-wiki-en.readthedocs.io/en/latest/tutorials/new_product/mid360/livox_eth_protocol_mid360.html).

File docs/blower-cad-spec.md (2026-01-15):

# Blower System CAD Specification

**Document Version:** 1.0
**Date:** 2026-01-14
**Status:** Draft
**Author:** Muni Robotics

## 1. Overview

### 1.1 System Architecture

The blower system integrates a commercial 90mm Electric Ducted Fan (EDF) motor/impeller unit into the BVR chassis via a custom 3D printed air handling system. The assembly consists of three primary components:

1. **Volute housing** - Converts radial airflow from the centrifugal impeller into directed axial flow
2. **Expansion nozzle** - Transitions from 90mm circular to 500mm × 30mm rectangular slot
3. **Shell integration** - Mounting hardware and cutouts for the powder-coated aluminum chassis shell

### 1.2 Design Goals

- **Exit velocity:** 120-140 MPH (54-63 m/s)
- **Volumetric flow:** 400-500 CFM (11.3-14.2 m³/min)
- **Outdoor durability:** ASA filament with UV and thermal resistance
- **Maintainability:** Tool-free impeller access, field-replaceable parts
- **Safety:** No exposed rotating components, guarded intake

### 1.3 Performance Requirements

| Parameter | Target | Notes |
|---|---|---|
| Exit velocity | 120-140 MPH | Measured at nozzle exit |
| Exit slot dimensions | 500mm × 30mm | Rectangular cross-section |
| Expansion angle | ≤15° half-angle | Prevents flow separation |
| Discharge angle | 20° downward | For snow clearing effectiveness |
| Motor power | 1500-2000W | Commercial EDF unit |
| Impeller diameter | 90mm | Pre-balanced assembly |

---

## 2. Volute Housing Specifications

### 2.1 Geometry

The volute housing captures radial airflow from the centrifugal impeller and converts it to directed axial flow. Design follows classic centrifugal scroll principles:

```
Top view (impeller rotation CW when viewed from front):

        ╭─────────╮
       ╱           ╲
      │    EDF      │  ← Motor mounting face
      │  Impeller   │
       ╲           ╱
        ╰─────┬───╯
              │
         ╔════▼════╗  ← Volute scroll (expanding radius)
         ║         ║
         ║    O    ║  ← Impeller center
         ║         ║
         ╚════╤════╝
              │
              └────→ To expansion nozzle (90mm outlet)

Side view:

    ┌─────────┐
    │  Motor  │
    │  Mount  │
    └────┬────┘
         │
    ╔════▼════╗
    ║ Volute  ║ ← 3-4mm wall thickness
    ╚════╤════╝
         │
         └────→ 90mm circular outlet
```

**Scroll profile:**
- Start radius: 46mm (just outside impeller tip clearance of 1mm)
- End radius: 65mm (at cutoff)
- Spiral angle: 270° wrap
- Cutoff angle: 90° from outlet centerline
- Tongue clearance: 2mm from impeller tip

**Dimensions:**
- Inlet diameter: 90mm (impeller OD + 2mm clearance)
- Outlet diameter: 90mm (circular, concentric transition to nozzle)
- Housing depth: 55mm (accommodates 50mm impeller + 5mm clearance)
- Overall diameter: 140mm (maximum at spiral end)

### 2.2 Material Specifications

**Primary material:** ASA (Acrylonitrile Styrene Acrylate)
- UV resistant (outdoor use)
- Glass transition temp: 100°C (adequate for motor heat)
- Impact resistant
- Minimal moisture absorption

**Print settings:**
- Layer height: 0.2mm
- Wall thickness: 3-4mm (12-16 perimeters at 0.4mm nozzle)
- Infill: 30% gyroid or honeycomb
- Top/bottom layers: 5 layers minimum

### 2.3 Motor Mounting Interface

The volute front face provides mounting for the commercial EDF motor unit.

**Mounting bolt pattern:**
- 4× M4 threaded inserts (heatset brass, 5mm OD × 6mm length)
- Bolt circle diameter: 100mm (verify against actual EDF motor)
- Counterbore depth: 2mm (flush M4 socket head cap screws)

**Impeller inlet:**
- Central hole diameter: 92mm (allows impeller hub passage)
- Stepped recess: 1mm deep × 95mm diameter (motor housing flange seat)
- O-ring groove: 3mm wide × 2mm deep at 97mm diameter (optional air seal)

**Alignment features:**
- 2× dowel pin holes: 4mm diameter × 6mm deep, 180° opposed
- Locating boss: 85mm diameter × 2mm height (concentric pilot)

### 2.4 Outlet Interface

**Outlet flange:**
- OD: 110mm
- ID: 90mm
- Thickness: 5mm
- Bolt holes: 4× M5, 100mm bolt circle, 90° spacing

**Sealing surface:**
- Flat face (±0.2mm flatness)
- Optional gasket groove: 2mm wide × 1mm deep

### 2.5 Print Orientation and Supports

**Recommended orientation:**
- Outlet flange face DOWN on build plate
- Motor mounting face UP
- Minimizes support material inside airflow path

**Support requirements:**
- Tree supports for scroll undercuts
- Support interface layer: 0.2mm gap
- Avoid supports on motor mounting face (use support blockers)

**Post-processing:**
- Remove supports carefully with flush cutters
- Light sanding of internal scroll surface (220 grit)
- Insert heatset inserts at 250°C with soldering iron tip

**Estimated print time:** 14-18 hours (0.4mm nozzle, 0.2mm layers)

---

## 3. Expansion Nozzle Specifications

### 3.1 Transition Geometry

The expansion nozzle smoothly transitions circular flow to rectangular slot output while maintaining attached flow (no separation).

```
Side view (vertical transition):

Inlet:  ⌒⌒⌒  90mm diameter
        ║ ║
        ║ ║  ← Gradual taper (15° half-angle max)
        ║ ║
       ╔═══╗
      ╔════╗
     ╔═════╗
    ╔══════╗ 30mm height
    ╚══════╝
Outlet: 500mm × 30mm slot

Top view (horizontal transition):

Inlet:   ╭─╮  90mm diameter
         │ │
        ╭───╮
       ╭─────╮
      ╭───────╮
     ╭─────────╮
    ╭───────────╮
   ╭─────────────╮
  ╔═══════════════╗ 500mm width
  ╚═══════════════╝
```

**Transition profile:**
- Inlet: 90mm diameter (circular)
- Outlet: 500mm × 30mm (rectangular with rounded corners)
- Length: 300mm (measured along centerline)
- Expansion half-angle: 14.5° vertical, 38° horizontal
- Wall thickness: 3mm minimum

**Notes on geometry:**
- Vertical expansion is gentle (14.5° < 15° limit, prevents separation)
- Horizontal expansion is aggressive (38° > 15°) BUT acceptable because:
  - Short aspect ratio transition
  - Exit velocity remains high (prevents backflow)
  - Slight turbulence acceptable for snow clearing (not precision airflow)
- Alternatively, split into two stages if testing shows separation issues

**Corner radii:**
- Inlet to nozzle: 10mm blend radius (smooth transition)
- Outlet corners: 15mm radius (reduces stress concentration)

### 3.2 Mounting to Volute

**Inlet flange:**
- OD: 110mm (matches volute outlet flange)
- ID: 90mm
- Thickness: 5mm
- Bolt holes: 4× M5 clearance (5.5mm diameter), 100mm bolt circle

**Assembly:**
- Gasket: 1mm silicone sheet or EPDM foam (optional, reduces vibration)
- Fasteners: 4× M5 × 20mm socket head cap screws
- Torque: 4-5 Nm (thread locker recommended)

### 3.3 Discharge Angle

The nozzle is angled 20° downward relative to horizontal chassis plane for optimal snow clearing.

```
Side view showing angle:

Chassis reference ─────────────
                ╲
              20° ╲  ← Nozzle centerline
                   ╲
                    ╲___  Ground interaction zone
                         ╲
```

**Implementation:**
- The 20° angle is built into the nozzle body geometry
- Nozzle mounts square to volute (volute provides the angle)
- Volute mounting brackets set the 20° pitch relative to chassis

### 3.4 Outlet Features

**Reinforcement:**
- 5mm thick flange around entire outlet perimeter
- 3mm internal ribs every 100mm along length (prevents flexing)

**Edge treatment:**
- 2mm radius on all sharp edges (safety, reduces wear on rubber snow skirt)

**Outlet sealing surface:**
- Flat face for rubber snow containment skirt attachment
- 3mm × 3mm step recess inboard (skirt capture groove)

### 3.5 Print Orientation and Supports

**Recommended orientation:**
- Inlet flange DOWN on build plate
- Outlet facing UP
- Nozzle axis parallel to build plate Y-axis (maximizes strength in longest dimension)

**Support requirements:**
- Supports needed under horizontal expansion surfaces
- Use organic tree supports (follows curves better than linear)
- 0.2mm support gap

**Segmentation option:**
If nozzle exceeds build volume (>350mm printers), split into two pieces:
- Joint at 150mm from inlet (mid-length)
- 10mm lap joint with 6× M4 threaded inserts
- Seal with silicone caulk during assembly

**Estimated print time:** 20-28 hours (monolithic), 12-16 hours per half (segmented)

---

## 4. Shell Integration

### 4.1 Shell Front Panel Cutout

The powder-coated aluminum shell front panel requires a precise cutout for the nozzle outlet.

**Cutout dimensions:**
- Width: 500mm (matches nozzle outlet)
- Height: 50mm (30mm slot + 10mm clearance top/bottom)
- Corner radius: 15mm (matches nozzle, reduces stress)
- Location: Centered horizontally, 120mm above chassis bottom plane

**Edge treatment:**
- Debur all edges (file or tumble after laser cutting)
- Optional: 2mm foam weather seal around perimeter (adhesive backed EPDM)

**Clearance:**
- 10mm gap around nozzle outlet (allows thermal expansion, vibration)

### 4.2 Mounting Points to Chassis

The blower assembly mounts to the 2020 aluminum extrusion chassis frame using custom brackets.

**Volute mounting brackets (2×):**
```
Side view of bracket:

    ╔════════╗  ← Volute mounting face (vertical)
    ║        ║
    ║  M5    ║  ← Threaded holes in volute body
    ║        ║
    ╚═══╤════╝
        │
        └─┐ 90° bend
          │
      ┌───┴────┐  ← 2020 extrusion mounting face (horizontal)
      │  ╱  ╲  │  ← T-nut slot clearance
      │ O    O │  ← M5 clearance holes for T-nuts
      └────────┘
```

**Bracket specifications:**
- Material: 3mm aluminum plate or 5mm ASA printed part
- Volute interface: 2× M5 threaded inserts per bracket
- Chassis interface: 2× M5 T-slot nuts per bracket (1010 series)
- Angle: Bracket provides 20° pitch (nozzle points downward)

**T-slot nut specifications:**
- Style: Drop-in T-nut (2020 compatible)
- Fastener: M5 × 12mm button head cap screw
- Torque: 5-6 Nm

**Nozzle support bracket (1×):**
- Attaches to nozzle outlet flange underside
- Mounts to chassis cross-member with 2× M5 T-nuts
- Prevents cantilever stress on volute outlet

### 4.3 Intake Vents

Air intake vents in the shell rear panel supply the blower system.

**Vent specifications:**
- Location: Top rear panel, above motor
- Total area: 100-150mm² (1.1-1.7× blower inlet area)
- Pattern: 12× 10mm diameter holes in 3×4 grid
- Spacing: 25mm centers
- Baffle: Internal deflector plate (prevents direct water ingress)

```
Rear panel (exterior view):

    Shell surface
    ┌─────────────────┐
    │  O   O   O   O  │  ← 10mm holes
    │                 │
    │  O   O   O   O  │
    │                 │
    │  O   O   O   O  │
    └─────────────────┘

Interior baffle (angled deflector):

          Air path
            ↓  ↓  ↓
    Shell ─┬───────┬─
           │  ╱ ╲  │ ← 45° baffle
           │╱     ╲│
           └───────┘ → To motor inlet
```

**Baffle mount:**
- 3D printed ASA part
- Clip-fit to shell interior or M3 fasteners
- 45° angle deflects water down and out

### 4.4 Drain Holes

Prevent water accumulation in blower housing cavity.

**Drain hole specifications:**
- Location: Bottom corners of shell cavity (2×)
- Diameter: 6mm
- Grommet: Rubber edge trim grommet (prevents chafing)
- Position: Lowest point when chassis is level

**Drainage path:**
- Holes positioned to drain water that enters via intake vents
- Not directly under motor (electronics protection)

---

## 5. CAD Checklist

### 5.1 Critical Dimensions to Verify

**Before finalizing CAD, measure and verify:**

- [ ] EDF motor mounting bolt pattern (may vary by manufacturer)
- [ ] EDF motor housing OD and flange thickness
- [ ] Impeller outer diameter (should be 90mm ±1mm)
- [ ] Impeller hub projection (volute inlet clearance)
- [ ] 2020 extrusion T-slot dimensions (verify drop-in T-nut fit)
- [ ] Shell front panel thickness (affects cutout edge clearance)
- [ ] Chassis mounting points (exact X/Y/Z coordinates for brackets)
- [ ] Ground clearance at nozzle outlet (min 50mm when pitched 20°)

### 5.2 Clearances to Check

**Use CAD interference detection:**

- [ ] Impeller to volute scroll clearance: 1-2mm (360° around)
- [ ] Motor housing to volute front face: No interference on bolt heads
- [ ] Nozzle outlet to shell cutout: 10mm gap all around
- [ ] Blower assembly to chassis frame: 15mm min clearance (vibration)
- [ ] Intake vents to motor inlet: Unobstructed air path
- [ ] Drain holes to ground: Holes not blocked when rover on flat surface
- [ ] Cable routing: 25mm clearance for motor power cable (12AWG)

### 5.3 Assembly Order Verification

**Simulate assembly in CAD to confirm:**

1. [ ] Install heatset inserts into volute (before mounting motor)
2. [ ] Attach motor to volute (4× M4 screws accessible with hex key)
3. [ ] Mount volute brackets to 2020 extrusion (T-nuts slide in from end)
4. [ ] Attach volute assembly to brackets (4× M5 screws)
5. [ ] Bolt nozzle to volute outlet flange (4× M5 screws from inside)
6. [ ] Install nozzle support bracket to chassis
7. [ ] Slide shell over chassis (nozzle outlet passes through cutout)
8. [ ] No interference or trapped fasteners

### 5.4 Stress Analysis Considerations

**Structural checks (if using FEA simulation):**

- [ ] Nozzle cantilever load: 2kg mass at outlet (simulates impact)
- [ ] Motor vibration: 50Hz excitation, 5G peak (unbalanced impeller scenario)
- [ ] Mounting bracket bending: 10kg load at volute center of mass
- [ ] Thermal expansion: 60°C operating temp (ASA Tg check)

**Target safety factor:** 2.5× minimum for printed parts

### 5.5 STL Export Settings

**For manufacturing-ready STL files:**

- [ ] Resolution: 0.01mm tolerance (high quality)
- [ ] Units: Millimeters
- [ ] Repair mesh: Close holes, fix normals
- [ ] Orientation: Part in print orientation (correct Z-axis)
- [ ] File naming: `blower-volute-v1.0.stl`, `blower-nozzle-v1.0.stl`
- [ ] Manifold check: All edges shared by exactly 2 faces
- [ ] Scale verification: Import into slicer and measure known dimension

---

## 6. Bill of Materials - 3D Printed Parts

| Part Name | Quantity | Material | Est. Weight | Est. Print Time | Notes |
|---|---|---|---|---|---|
| Volute housing | 1 | ASA | 450g | 16h | Includes motor mount |
| Expansion nozzle | 1 | ASA | 800g | 24h | Monolithic version |
| Expansion nozzle (half A) | 1 | ASA | 420g | 14h | Segmented version |
| Expansion nozzle (half B) | 1 | ASA | 420g | 14h | Segmented version |
| Intake baffle | 1 | ASA | 40g | 2h | Water deflector |
| Volute mounting bracket | 2 | ASA | 60g ea. | 3h ea. | Alt: 3mm aluminum |
| Nozzle support bracket | 1 | ASA | 50g | 2.5h | Outlet stabilizer |

**Total print time (monolithic nozzle):** ~42 hours
**Total print time (segmented nozzle):** ~51 hours
**Total filament:** ~1.5 kg ASA

**Hardware (not printed):**
- 4× M4 × 12mm socket head cap screws (motor to volute)
- 4× M4 heatset inserts, 5mm OD × 6mm length
- 8× M5 × 20mm socket head cap screws (nozzle to volute, brackets to volute)
- 8× M5 × 12mm button head cap screws (brackets to chassis T-nuts)
- 8× M5 drop-in T-nuts, 2020 series
- 6× M4 × 16mm socket head cap screws (nozzle segment joint, if segmented)
- 12× M4 heatset inserts (nozzle segment joint, if segmented)
- 1× Silicone caulk tube (assembly sealing)
- 2× Rubber edge trim grommets, 6mm ID (drain holes)

**Print settings reminder:**
- Nozzle: 0.4mm
- Layer height: 0.2mm
- Wall thickness: 3-4mm (12-16 perimeters)
- Infill: 30% gyroid
- Material: ASA (outdoor rated)
- Bed temp: 100°C, nozzle temp: 250°C
- Enclosure: Required (ASA warps without)

---

## 7. Design Notes and Rationale

### 7.1 Why ASA Over Other Materials

**ASA selected over alternatives:**
- **vs. PLA:** PLA softens at 60°C (inadequate for summer outdoor use)
- **vs. PETG:** PETG creeps under sustained load, absorbs moisture
- **vs. ABS:** ASA has superior UV resistance (ABS yellows and degrades)
- **vs. Nylon:** Nylon requires dry box storage, expensive, hygroscopic
- **vs. Polycarbonate:** PC is overkill (more difficult to print, unnecessary strength)

### 7.2 Expansion Angle Trade-offs

The nozzle horizontal expansion (38° half-angle) exceeds the classical 15° diffuser limit. This is acceptable because:

1. **Application context:** Snow clearing tolerates turbulence (not a precision air bearing)
2. **High exit velocity:** 120+ MPH prevents backflow even with separation
3. **Short length:** 300mm transition limits separation region
4. **Alternative:** Two-stage expansion (adds complexity, print time, leak potential)

**Testing plan:** If field testing shows poor performance (low velocity, high motor current), redesign as two-stage:
- Stage 1: 90mm circular → 200mm × 45mm (15° vertical, 15° horizontal)
- Stage 2: 200mm × 45mm → 500mm × 30mm (gradual rectangular morph)

### 7.3 Print Segmentation Decision

**Monolithic nozzle:**
- Pros: No joints, no leaks, stronger
- Cons: Requires ≥350mm build plate, long print time

**Segmented nozzle:**
- Pros: Fits smaller printers (250mm class), easier re-printing if damaged
- Cons: Joint requires sealing, slight performance loss

**Recommendation:** Print monolithic if printer allows. Use segmented as fallback.

### 7.4 Mounting Strategy

The blower mounts to 2020 extrusion (not directly to shell) because:
- Shell is cosmetic, not structural
- Vibration isolation (shell floats on rubber mounts)
- Serviceability (remove shell without disturbing blower)
- Load path (blower forces go directly to chassis frame)

---

## 8. Future Enhancements

**Potential improvements for future revisions:**

1. **Active cooling:** Add 40mm axial fan to motor housing (extends duty cycle)
2. **Vibration damping:** Rubber isolators at mounting brackets (reduces noise)
3. **Modular nozzles:** Quick-change outlet inserts (different slot widths for tuning)
4. **Sensor integration:** Anemometer at outlet (measure actual velocity, closed-loop control)
5. **Sound attenuation:** Internal acoustic foam lining (reduces 6-8kHz whine)

---

## Appendices

### A. Reference Standards

- **Centrifugal fan design:** AMCA 210 (Air Movement and Control Association)
- **Diffuser expansion limits:** Fluid Mechanics, White (McGraw-Hill), Chapter 6
- **ASA material properties:** ASTM D638 (tensile), ASTM D648 (heat deflection)

### B. CAD Software Recommendations

- **Fusion 360:** Excellent for sheet metal shell, T-slot frame modeling
- **SolidWorks:** Industry standard, parametric design
- **Onshape:** Cloud-based, free for public projects
- **FreeCAD:** Open-source option

### C. Print Service Specifications

If outsourcing 3D printing:

**Material:** ASA (UV stabilized)
**Layer height:** 0.2mm
**Infill:** 30% minimum
**Wall thickness:** 4mm
**Finish:** As-printed (no post-processing required)
**Tolerances:** ±0.2mm on mounting features, ±0.5mm on airflow surfaces
**Delivery format:** Upload STL files, specify print orientation in notes

---

**END OF SPECIFICATION**

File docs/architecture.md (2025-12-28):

# BVR Architecture

**Base Vectoring Rover** — Muni's foundational mobile platform.

## Overview

```
┌─────────────────────────────────────────────────────────────────────────────┐
│                              Operator Station                                │
│  ┌─────────────────────────────────────────────────────────────────────┐   │
│  │  Desktop App                                                         │   │
│  │  ┌─────────────┐  ┌─────────────┐  ┌────────────────────────────┐  │   │
│  │  │ Video View  │  │ Xbox Ctrl   │  │ Telemetry                  │  │   │
│  │  │ (H.265)     │  │ (gamepad)   │  │ (voltage, temps, mode)     │  │   │
│  │  └─────────────┘  └─────────────┘  └────────────────────────────┘  │   │
│  └───────────────────────────────┬─────────────────────────────────────┘   │
│                                  │ QUIC / UDP                               │
└──────────────────────────────────┼─────────────────────────────────────────┘
                                   │
                    ┌──────────────┴──────────────┐
                    │       Cloud Relay           │
                    │  (optional, for NAT)        │
                    └──────────────┬──────────────┘
                                   │ LTE
┌──────────────────────────────────┼─────────────────────────────────────────┐
│                                  │                                   Rover │
│  ┌───────────────────────────────┴─────────────────────────────────────┐   │
│  │  bvrd (Jetson Orin NX)                                              │   │
│  │                                                                      │   │
│  │  ┌────────────┐  ┌────────────┐  ┌────────────┐  ┌──────────────┐  │   │
│  │  │ teleop     │  │ control    │  │ state      │  │ tools        │  │   │
│  │  │            │  │            │  │            │  │              │  │   │
│  │  │ • Commands │  │ • Mixer    │  │ • Modes    │  │ • Discovery  │  │   │
│  │  │ • Telemetry│  │ • Limiter  │  │ • E-Stop   │  │ • Snow auger │  │   │
│  │  │ • Video    │  │ • Watchdog │  │            │  │ • (future)   │  │   │
│  │  └──────┬─────┘  └──────┬─────┘  └──────┬─────┘  └──────┬───────┘  │   │
│  │         │               │               │               │          │   │
│  │         └───────────────┴───────────────┴───────────────┘          │   │
│  │                                │                                    │   │
│  │                           ┌────┴────┐                               │   │
│  │                           │   can   │                               │   │
│  │                           │  (VESC) │                               │   │
│  │                           └────┬────┘                               │   │
│  └────────────────────────────────┼────────────────────────────────────┘   │
│                                   │ CAN bus                                │
│       ┌───────────┬───────────────┼───────────────┬───────────┐           │
│       │           │               │               │           │           │
│  ┌────┴────┐ ┌────┴────┐    ┌────┴────┐    ┌────┴────┐ ┌────┴─────┐     │
│  │ VESC FL │ │ VESC FR │    │ VESC RL │    │ VESC RR │ │ Tool MCU │     │
│  │ ID=1    │ │ ID=2    │    │ ID=3    │    │ ID=4    │ │ (RP2040) │     │
│  └────┬────┘ └────┬────┘    └────┬────┘    └────┬────┘ └────┬─────┘     │
│       │           │               │               │           │           │
│  ┌────┴────┐ ┌────┴────┐    ┌────┴────┐    ┌────┴────┐ ┌────┴─────┐     │
│  │ Hub     │ │ Hub     │    │ Hub     │    │ Hub     │ │ Snow     │     │
│  │ Motor   │ │ Motor   │    │ Motor   │    │ Motor   │ │ Auger    │     │
│  └─────────┘ └─────────┘    └─────────┘    └─────────┘ └──────────┘     │
└─────────────────────────────────────────────────────────────────────────────┘
```

## Hardware

| Component | Specification |
| --- | --- |
| Compute | Jetson Orin NX |
| Chassis | 24×24" 2020 aluminum extrusion |
| Motors | 4× hoverboard hub motors |
| ESCs | 4× VESC (CAN bus) |
| Power | 48V main, 12V accessory rail |
| Connectivity | Ubiquiti 5 GHz mesh |

## Software Crates

| Crate | Purpose |
| --- | --- |
| `types` | Shared types (Twist, Mode, etc.) |
| `can` | CAN bus + VESC protocol |
| `control` | Differential drive mixer, rate limiter, watchdog |
| `state` | State machine (Disabled → Idle → Teleop/Autonomous → EStop) |
| `hal` | GPIO, ADC, power monitoring |
| `teleop` | LTE communications, command/telemetry |
| `tools` | Tool discovery and implementations |
| `recording` | Session recording to Rerun .rrd files |
| `metrics` | Real-time metrics push to Depot (InfluxDB UDP) |
| `gps` | GPS receiver (NMEA parsing) |
| `camera` | Camera capture and video streaming |

## Binaries

| Binary | Purpose |
| --- | --- |
| `bvrd` | Main daemon — runs on the Jetson |
| `cli`  | Debug/control CLI tool |

## Threading Model

```
bvrd process
│
├── Main thread (control loop, 100Hz)
│   ├── Read CAN frames
│   ├── Process commands from channel
│   ├── Update state machine
│   ├── Compute motor outputs
│   ├── Send CAN commands
│   └── Update telemetry
│
└── Tokio runtime (async)
    └── Teleop server task
        ├── Receive UDP commands
        └── Send UDP telemetry
```

## State Machine

```
                    ┌──────────┐
                    │ Disabled │◄─────────────────────┐
                    └────┬─────┘                      │
                         │ Enable                     │ Disable
                         ▼                            │
                    ┌──────────┐                      │
         ┌──────────│   Idle   │──────────┐          │
         │          └────┬─────┘          │          │
         │ Teleop Cmd    │ Autonomous     │          │
         ▼               ▼                │          │
    ┌──────────┐   ┌────────────┐        │          │
    │  Teleop  │◄─►│ Autonomous │        │          │
    └────┬─────┘   └─────┬──────┘        │          │
         │               │                │          │
         │ E-Stop        │ E-Stop         │          │
         └───────┬───────┘                │          │
                 ▼                        │          │
            ┌──────────┐                  │          │
            │  E-Stop  │──────────────────┘          │
            └────┬─────┘                             │
                 │ Release                           │
                 └───► Idle                          │
                                                     │
            ┌──────────┐                             │
            │  Fault   │─────────────────────────────┘
            └──────────┘
              Clear
```

## Data Flow

1. **Operator → Rover**

   - Xbox controller input → Operator app
   - Twist command serialized → UDP packet
   - LTE → Cloud relay → Rover
   - `teleop` receives → sends to `bvrd` via channel

2. **Rover → Operator**

   - `bvrd` reads VESC status via CAN
   - Builds telemetry struct
   - `teleop` serializes → UDP packet
   - Rover → Cloud relay → LTE → Operator app

3. **Tool Control**

   - Xbox RT/LT + A button → Tool command
   - `tools` registry routes to active tool
   - Tool outputs CAN command
   - Tool MCU executes

4. **Rover → Depot (Base Station)**
   - Real-time: `metrics` crate → UDP → InfluxDB (1Hz)
   - Sessions: `recording` crate → .rrd files → rclone → SFTP (every 15 min)
   - Dashboards: Grafana queries InfluxDB for fleet status

## Configuration

Runtime configuration is in `config/bvr.toml`:

```toml
[chassis]
wheel_diameter_m = 0.165
track_width_m = 0.55
wheelbase_m = 0.55

[can]
interface = "can0"
vesc_ids = [1, 2, 3, 4]
pole_pairs = 15

[control]
loop_rate_hz = 100
command_timeout_ms = 250

[teleop]
port = 4840
```

## Safety

1. **Watchdog**: No command for 250ms → safe stop
2. **E-Stop**: Immediate stop, requires explicit release
3. **Rate limiting**: Acceleration capped to prevent tip-over
4. **Voltage monitoring**: Low battery → reduced power → shutdown

## Logging and Telemetry

BVR uses a multi-layer approach:

1. **Event Logging** (`tracing`): Text logs to stdout and rolling files
2. **Telemetry Recording** (`recording`): Time-series data to Rerun .rrd files
3. **Real-time Metrics** (`metrics`): Live telemetry push to Depot via InfluxDB UDP

Sessions and logs are automatically synced to Depot (base station) for analysis.

See [docs/logging.md](logging.md) for rover-side details and [depot/README.md](../depot/README.md) for base station setup.

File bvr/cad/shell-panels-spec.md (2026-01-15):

# BVR1 Shell Panel Specifications for SendCutSend

**Document Version:** 1.0
**Date:** 2026-01-15
**Material:** 5052 Aluminum, 2mm thickness
**Finish:** Orange powder coat

## Overview

Shell panels to cover the BVR1 chassis frame (380mm × 500mm × 180mm).

## Panel Dimensions

All dimensions in millimeters. Shell provides 20mm clearance around frame.

### 1. Front Panel

**Dimensions:** 420mm wide × 200mm tall

**Cutouts:**
- Blower nozzle slot: 500mm × 50mm, centered horizontally, bottom edge 100mm from panel bottom
  - Corner radius: 15mm
- Mounting holes: 8× M5 (5.3mm) holes on 10mm inset from edges

```
    420mm
┌───────────────────────────────────────────┐
│  ○                                     ○  │  ← M5 holes, 10mm from edge
│                                           │
│           ┌───────────────────┐           │  ← Nozzle slot: 500mm × 50mm
│           │                   │           │    centered, 100mm from bottom
│           │   500mm × 50mm    │           │
│           │    R15 corners    │           │
│           └───────────────────┘           │
│                                           │
│  ○                                     ○  │
└───────────────────────────────────────────┘
    200mm
```

### 2. Rear Panel

**Dimensions:** 420mm wide × 200mm tall

**Cutouts:**
- Intake vent: 12× 10mm diameter holes in 3×4 grid
  - Grid: 3 columns × 4 rows, 25mm spacing
  - Grid centered at 210mm from left, 150mm from bottom
- Drain holes: 2× 6mm holes at bottom corners (20mm inset)
- Mounting holes: 8× M5 (5.3mm) holes on 10mm inset from edges

```
    420mm
┌───────────────────────────────────────────┐
│  ○                                     ○  │
│                                           │
│              ○   ○   ○   ○                │  ← Intake vents: 12× 10mm
│              ○   ○   ○   ○                │    25mm spacing
│              ○   ○   ○   ○                │
│                                           │
│  ○                                     ○  │
│                                           │
│  ◐                                     ◐  │  ← 6mm drain holes
└───────────────────────────────────────────┘
    200mm
```

### 3. Side Panels (×2, mirror)

**Dimensions:** 540mm long × 200mm tall

**Cutouts:**
- Mounting holes: 10× M5 (5.3mm) holes on 10mm inset from edges
- Motor access cutout (optional): 100mm × 80mm at wheel locations

```
    540mm
┌───────────────────────────────────────────────────────────┐
│  ○        ○                            ○        ○         │
│                                                           │
│                                                           │
│  ○        ○                            ○        ○         │
│                                                           │
│  ○                                                     ○  │
└───────────────────────────────────────────────────────────┘
    200mm
```

### 4. Top Panel

**Dimensions:** 420mm wide × 540mm long

**Cutouts:**
- Sensor mast hole: 30mm diameter, centered at 210mm × 450mm (rear section)
- E-stop access: 30mm diameter, centered at 350mm × 100mm (front right)
- Mounting holes: 12× M5 (5.3mm) holes around perimeter

```
                    420mm
┌───────────────────────────────────────────┐
│  ○           ○           ○           ○    │
│                                           │
│                        ◎ ← E-stop (30mm)  │
│  ○                                     ○  │
│                                           │
│                                           │
│  ○                                     ○  │
│                                           │
│               ◎ ← Sensor mast (30mm)      │
│                                           │
│  ○           ○           ○           ○    │
└───────────────────────────────────────────┘
                    540mm
```

## Bending Requirements

None required for initial version. Panels are flat, assembled with L-brackets.

## Assembly Hardware

- 38× M5 × 10mm button head cap screws
- 38× M5 T-slot nuts (2020 compatible)
- 4× 90° corner brackets (hidden inside)
- Weather seal tape for panel joints (optional)

## SendCutSend Order Details

| Panel | Qty | Material | Thickness | Finish | Est. Cost |
|---|-----|---|---|---|---|
| Front | 1 | 5052-H32 | 2mm | Orange powder | ~$25 |
| Rear | 1 | 5052-H32 | 2mm | Orange powder | ~$25 |
| Side (L) | 1 | 5052-H32 | 2mm | Orange powder | ~$30 |
| Side (R) | 1 | 5052-H32 | 2mm | Orange powder | ~$30 |
| Top | 1 | 5052-H32 | 2mm | Orange powder | ~$35 |
| **Total** | 5 | | | | **~$145** |

*Note: Prices are estimates. Actual cost depends on SendCutSend pricing.*

## DXF File Checklist

Generate these DXF files:
- [ ] `shell-front.dxf` - Front panel with nozzle cutout
- [ ] `shell-rear.dxf` - Rear panel with intake vents and drains
- [ ] `shell-side-left.dxf` - Left side panel
- [ ] `shell-side-right.dxf` - Right side panel (mirror of left)
- [ ] `shell-top.dxf` - Top panel with sensor and E-stop holes

## Notes

1. **Front panel nozzle cutout**: Per blower-cad-spec.md, the slot is 500mm × 50mm with 15mm corner radii
2. **Intake vents**: 12× 10mm holes provide 100-150% of blower inlet area
3. **Drain holes**: Positioned at lowest points when rover is level
4. **Powder coat**: Orange color to match Muni brand (RAL 2004 or similar)
5. **Edge treatment**: All edges deburred, no sharp corners

## DXF Generation

To generate DXF files, use one of:
1. **FreeCAD**: Import this spec, draw geometry, export DXF
2. **LibreCAD**: Direct 2D CAD drawing
3. **OpenSCAD**: Script geometry, export DXF
4. **Online tools**: dxf-creator.com or similar

Example LibreCAD workflow:
1. Create new drawing (mm units)
2. Draw rectangle for panel outline
3. Draw cutout geometries
4. Add mounting holes (circles)
5. Export as DXF (R12 format for compatibility)

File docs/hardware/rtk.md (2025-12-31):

# RTK GPS

Centimeter-accurate positioning for georeferenced mapping.

## Quick Start

```bash
# Install the muni CLI
cd bvr/firmware && cargo install --path bins/cli

# Configure base station (with known coordinates)
muni gps configure-base --port /dev/tty.usbmodem1101 \
    --fixed-position 41.481956,-81.8053,213.5

# Configure rover
muni gps configure-rover --port /dev/ttyACM0

# Monitor GPS status (works for both base and rover)
muni gps monitor --port /dev/tty.usbmodem1101
```

Press `q`, `Esc`, or `Ctrl+C` to exit the monitor.

## Overview

RTK (Real-Time Kinematic) GPS uses corrections from a base station to achieve
±1-2cm positioning accuracy, compared to ±2-5m with standard GPS.

```
┌─────────────────────────────────────────────────────────────────────────────┐
│                              RTK Architecture                                │
│                                                                              │
│  ┌─────────────────────────────────────────────────────────────────────┐   │
│  │                         Depot (Base Station)                         │   │
│  │                                                                       │   │
│  │  ┌─────────────┐    ┌─────────────┐    ┌─────────────────────────┐  │   │
│  │  │ GNSS        │    │ ZED-F9P     │    │ NTRIP Caster            │  │   │
│  │  │ Antenna     │───►│ (Base Mode) │───►│ (broadcasts corrections)│  │   │
│  │  │ (roof)      │    │ USB to Pi   │    │ Port 2101               │  │   │
│  │  └─────────────┘    └─────────────┘    └─────────────────────────┘  │   │
│  └─────────────────────────────────────────────────────────────────────┘   │
│                                     │                                        │
│                                     │ RTCM3 corrections                      │
│                                     │ (via 5 GHz mesh network)               │
│                                     ▼                                        │
│  ┌─────────────────────────────────────────────────────────────────────┐   │
│  │                         Rover (Receiver)                             │   │
│  │                                                                       │   │
│  │  ┌─────────────┐    ┌─────────────┐    ┌─────────────────────────┐  │   │
│  │  │ GNSS        │    │ ZED-F9P     │    │ gps crate               │  │   │
│  │  │ Antenna     │───►│ (Rover Mode)│───►│ (NMEA parsing)          │  │   │
│  │  │ (on rover)  │    │             │    │                          │  │   │
│  │  └─────────────┘    └─────────────┘    └─────────────────────────┘  │   │
│  └─────────────────────────────────────────────────────────────────────┘   │
└─────────────────────────────────────────────────────────────────────────────┘
```

RTK corrections are delivered over the Ubiquiti mesh network (see [networking.md](networking.md)).
The low latency (5-20ms vs 50-150ms with LTE) improves fix acquisition time.

## When You Need RTK

| Use Case | Standard GPS | RTK GPS |
| --- | --- | --- |
| Fleet tracking | ✅ Sufficient | Overkill |
| Rough geolocation | ✅ Sufficient | Overkill |
| Georeferenced mapping | ⚠️ ~3m error | ✅ ~2cm error |
| Multi-session map fusion | ❌ Drift issues | ✅ Consistent |
| Autonomous navigation | ⚠️ Lane-level | ✅ Centimeter |

**For bvr0**: Standard GPS is fine for prototyping.
**For bvr1**: RTK enables street-view quality georeferenced mapping.

## Hardware

### Rover Receiver

| Component  | Model | Price | Source |
| --- | --- | ----- | --- |
| GPS Module | [SparkFun GPS-RTK2 (ZED-F9P)](https://www.amazon.com/SparkFun-GPS-RTK2-Board-ZED-F9P-Qwiic/dp/B07NBPNWNZ) | ~$220 | Amazon |
| Antenna | SparkFun GNSS Multi-Band L1/L2 (active) | ~$75  | SparkFun |
| SMA Cable  | RG174, 1m | ~$10  | Amazon |
| U.FL-SMA | U.FL to SMA pigtail (if using breakout) | ~$8 | Amazon |

**Important:** The ZED-F9P requires a multi-band (L1+L2) active GNSS antenna. A standard WiFi
antenna will not work: you'll see "NO FIX" with 0 satellites. The SparkFun board has a U.FL
connector: use a U.FL to SMA pigtail to connect the antenna.

### Base Station (Depot)

| Component | Model | Price | Notes |
| --- | --- | ----- | --- |
| GPS Module | SparkFun GPS-RTK2 (ZED-F9P) | ~$220 | Same as rover |
| Antenna | Tallysman TW4721 (survey-grade) | ~$100 | Better multipath rejection |
| SMA Cable | LMR-400, 25ft | ~$40  | Low-loss for roof run |
| Raspberry Pi | Pi 4 (2GB+) | ~$50  | Runs NTRIP caster |

**Total base station: ~$410**

Alternatively, integrate into the depot server directly via USB.

## Rover Integration

### Hardware Connection

**Option 1: USB (Recommended for development)**

```
GNSS Antenna
     │
     │ U.FL → SMA pigtail → SMA cable
     ▼
┌─────────────┐
│ SparkFun    │
│ ZED-F9P     │
│             │
│ USB-C ──────┼──► Computer/Jetson USB
│             │    /dev/ttyACM0 (Linux)
│             │    /dev/tty.usbmodem* (macOS)
└─────────────┘
```

USB provides power and data. Default baud: 38400.

**Option 2: UART (Recommended for production)**

```
GNSS Antenna
     │
     │ SMA cable
     ▼
┌─────────────┐
│ SparkFun    │
│ ZED-F9P     │
│             │
│ TX ─────────┼──► Jetson UART (/dev/ttyTHS1)
│ RX ◄────────┼─── Jetson UART (for RTCM input)
│ VCC ◄───────┼─── 3.3V
│ GND ◄───────┼─── GND
└─────────────┘
```

For UART, configure the baud rate to 115200 for high-rate output.

### Software Integration

The ZED-F9P outputs standard NMEA, compatible with existing `gps` crate:

```rust
// Minimal change to gps crate
let gps = GpsReceiver::new("/dev/ttyTHS1", 115200)?;

// Position now has RTK accuracy when corrections are received
let fix = gps.get_fix()?;
println!("Position: {:.8}, {:.8} (accuracy: {:.2}m)",
    fix.latitude, fix.longitude, fix.horizontal_accuracy);
```

### NTRIP Client

To receive corrections from the depot base station over the mesh network:

```rust
// crates/gps/src/ntrip.rs

pub struct NtripClient {
    server: String,  // depot IP on mesh network
    port: u16,       // 2101
    mountpoint: String,
}

impl NtripClient {
    /// Connect to NTRIP caster and stream corrections to GPS receiver
    pub async fn run(&self, gps_tx: &mut dyn Write) -> Result<(), NtripError> {
        let stream = TcpStream::connect((self.server.as_str(), self.port)).await?;
        // ... NTRIP handshake ...

        loop {
            let rtcm_data = stream.read(...).await?;
            gps_tx.write_all(&rtcm_data)?;  // Forward to ZED-F9P UART
        }
    }
}
```

### Bandwidth Requirements

RTK corrections are lightweight and easily fit alongside teleop traffic:

| Stream | Bandwidth | Protocol |
| --- | --- | --- |
| RTCM3 corrections | 1-2 kbps  | TCP |
| NMEA output | <1 kbps | Serial |

For comparison, a single rover uses ~5 Mbps total for video and teleop.

## Base Station Setup

### Hardware Installation

1. **Mount antenna** on depot roof with clear sky view (no obstructions above 10°)
2. **Run SMA cable** through building to server rack
3. **Connect ZED-F9P** to depot server via USB
4. **Survey position** to establish precise base coordinates

### Survey Procedure

The base station must know its exact position. Options:

| Method | Accuracy | Time |
| --- | --- | --- |
| Self-survey (1hr) | ±1m | 1 hour |
| Self-survey (24hr)  | ±10cm | 24 hours |
| PPP service | ±2cm | Submit 24hr log, wait 1 week |
| Professional survey | ±1cm | Hire surveyor |

For most applications, 24-hour self-survey is sufficient:

```bash
# Configure ZED-F9P for survey-in mode (24hr, 10cm target)
muni gps configure-base --port /dev/ttyACM0 \
    --survey-duration 86400 \
    --survey-accuracy 0.1

# Monitor survey progress
muni gps monitor --port /dev/ttyACM0
```

If you know the exact coordinates (from a previous survey or professional surveyor):

```bash
# Configure with fixed position (lat,lon,alt in meters)
muni gps configure-base --port /dev/ttyACM0 \
    --fixed-position 41.481956,-81.8053,213.5
```

### NTRIP Caster

Run an NTRIP caster to broadcast corrections:

#### Option 1: Docker Container

```yaml
# depot/docker-compose.yml (addition)
services:
  ntrip:
    image: ghcr.io/rtcm/rtkbase:latest
    ports:
      - "2101:2101"
    devices:
      - /dev/ttyUSB0:/dev/ttyUSB0 # ZED-F9P
    volumes:
      - ./ntrip/config:/config
```

#### Option 2: SNIP (Windows/Linux)

[SNIP](http://www.use-snip.com/) is a popular NTRIP caster with a free tier.

#### Option 3: str2str (RTKLIB)

```bash
# Stream ZED-F9P output as NTRIP caster
str2str -in serial://ttyUSB0:115200 \
        -out ntrips://:password@:2101/ROVER
```

### Depot Server Integration

Add to depot services in `docker-compose.yml`:

```yaml
ntrip-caster:
  image: ghcr.io/rtcm/rtkbase:latest
  container_name: ntrip
  restart: unless-stopped
  ports:
    - "2101:2101"
  devices:
    - /dev/ttyUSB0:/dev/ttyUSB0
  volumes:
    - ntrip-config:/config

volumes:
  ntrip-config:
```

## Alternative: NTRIP Network

Instead of running your own base station, use a commercial NTRIP network:

| Provider | Coverage | Price |
| --- | --- | --- |
| [PointOne Nav](https://pointonenav.com/) | USA/EU | ~$50/mo |
| [Skylark](https://www.swiftnav.com/skylark) | Global | ~$50/mo |
| State DOT CORS | Varies | Free (some states) |

For a fleet operating in multiple regions, a network subscription may be
more practical than deploying base stations.

## Mounting

### Rover Antenna

- Mount on top of sensor pole (highest point)
- Clear sky view in all directions
- Ground plane improves multipath rejection

```
        ┌─────────┐
        │  GNSS   │  ← Top of stack
        │ Antenna │
        └────┬────┘
        ┌────┴────┐
        │Insta360 │
        │   X4    │
        └────┬────┘
        ┌────┴────┐
        │ Mid-360 │
        └────┬────┘
             │
         Rover
```

### Base Station Antenna

- Roof mount with unobstructed sky
- Away from metal structures, HVAC units
- Secure against wind
- Protect cable entry from weather

## Accuracy Expectations

| Condition | Horizontal | Vertical |
| --- | --- | --- |
| RTK fixed (ideal) | ±1cm | ±2cm |
| RTK float | ±20cm | ±40cm |
| DGPS (no RTK) | ±50cm | ±1m |
| Standard GPS | ±2-5m | ±5-10m |

RTK requires:

- Clear sky view (>5 satellites)
- Corrections from base station
- Base station within ~20km (for single-base RTK)

## Troubleshooting

### No RTK Fix

```bash
# Monitor satellite count, fix quality, and HDOP
muni gps monitor --port /dev/ttyACM0

# Verify NTRIP caster is running
curl -v http://depot:2101/
```

The monitor TUI shows:

- Fix quality (NO FIX, GPS, DGPS, RTK FLOAT, RTK FIXED)
- Satellite counts per constellation (GPS, GLONASS, Galileo, BeiDou)
- Signal strength bars for each satellite

### Frequent Fix Loss

- Check antenna placement (obstructions above 10° elevation?)
- Verify correction stream continuity
- Ensure multi-band active antenna (not a WiFi antenna!)
- Consider longer cable or better antenna

### Base Station Issues

```bash
# Monitor base station: shows survey-in progress and RTCM output
muni gps monitor --port /dev/ttyACM0
```

The base station monitor shows:

- Survey-in duration and accuracy
- RTCM message counts and types being broadcast
- Fixed position coordinates (after survey complete)

### Configuration Not Persisting

If the module reverts to NMEA output after power cycling:

```bash
# Reconfigure (settings are saved to flash)
muni gps configure-base --port /dev/ttyACM0 --fixed-position LAT,LON,ALT

# Power cycle the module, then verify
muni gps monitor --port /dev/ttyACM0
# Should show "BASE" mode, not "ROVER"
```

## CLI Reference

### muni gps monitor

Real-time TUI monitor for GNSS receivers. Auto-detects rover (NMEA) vs base (RTCM/UBX) mode.

```bash
muni gps monitor --port /dev/ttyACM0 [--baud 38400]
```

**Rover mode display:**

- Position (lat/lon/alt)
- Fix quality and satellite count
- Per-constellation satellite signal bars
- Raw NMEA log

**Base station mode display:**

- Survey-in progress (duration, accuracy, observations)
- RTCM message statistics (type, count, bytes)
- Fixed position coordinates

**Controls:** `q`, `Esc`, or `Ctrl+C` to quit.

### muni gps configure-base

Configure ZED-F9P as an RTK base station.

```bash
# Survey-in mode (determines position over time)
muni gps configure-base --port /dev/ttyACM0 \
    --survey-duration 3600 \
    --survey-accuracy 2.0

# Fixed position mode (use known coordinates)
muni gps configure-base --port /dev/ttyACM0 \
    --fixed-position 41.481956,-81.8053,213.5
```

This command:

- Disables NMEA output
- Enables RTCM3 messages (1005, 1074, 1084, 1094, 1124, 1230)
- Enables UBX-NAV-SVIN for survey status
- Configures time mode (survey-in or fixed)
- Saves configuration to flash (persists across power cycles)

### muni gps configure-rover

Configure ZED-F9P as an RTK rover.

```bash
muni gps configure-rover --port /dev/ttyACM0
```

This command:

- Enables NMEA output (GGA, RMC, GSV, GSA, VTG)
- Disables RTCM output
- Disables time mode
- Saves configuration to flash

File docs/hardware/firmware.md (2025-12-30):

# Firmware

Quick reference for building and flashing firmware.

## Components

| Component | Platform | Location | Protocol |
|---|---|---|---|
| bvrd | Jetson (aarch64) | `bvr/firmware/bins/bvrd/` | gRPC, CAN |
| Attachment | ESP32-S3 | `mcu/bins/esp32s3/` | SLCAN over USB |
| VESC | STM32 | External | CAN |

## bvrd (Jetson)

Main rover daemon handling motor control, sensors, and depot communication.

### Prerequisites

```bash
# Install Rust cross-compilation target
rustup target add aarch64-unknown-linux-gnu

# Install cross-linker (Ubuntu/Debian)
sudo apt install gcc-aarch64-linux-gnu
```

### Build

```bash
cd bvr/firmware
cargo build --release --target aarch64-unknown-linux-gnu
```

### Deploy

```bash
# Copy binary to Jetson
scp target/aarch64-unknown-linux-gnu/release/bvrd muni@<jetson-ip>:/opt/muni/bin/

# SSH to Jetson and restart
ssh muni@<jetson-ip>
sudo systemctl restart bvrd
sudo systemctl status bvrd
```

### Logs

```bash
# On Jetson
journalctl -u bvrd -f          # Follow logs
journalctl -u bvrd -n 100      # Last 100 lines
journalctl -u bvrd --since "1 hour ago"
```

---

## Attachment Firmware (ESP32-S3)

Runs on Heltec LoRa 32 V3 and compatible ESP32-S3 boards.

### Prerequisites

```bash
# Install ESP32 Rust toolchain
cargo install espup
espup install

# Add to shell profile
echo 'source ~/export-esp.sh' >> ~/.zshrc

# Install flasher
cargo install espflash
```

### Build

```bash
cd mcu/bins/esp32s3
source ~/export-esp.sh
cargo build --release
```

### Flash

```bash
espflash flash \
    --ignore-app-descriptor \
    --partition-table partitions.csv \
    --bootloader bootloader.bin \
    --min-chip-rev 0.0 \
    target/xtensa-esp32s3-none-elf/release/mcu-esp32s3
```

### Monitor

```bash
# Using espflash
espflash monitor

# Using screen
screen /dev/cu.usbserial-0001 115200
# Exit: Ctrl+A, K, Y
```

### Bootloader Mode

If the board won't flash:

1. Unplug USB
2. Hold BOOT/PRG button
3. Plug in USB (keep holding)
4. Release after 2 seconds
5. Retry flash command

### Features

Enable/disable features in `Cargo.toml`:

```toml
[features]
default = ["status-bar", "addressable-leds"]
status-bar = []        # 5 GPIO status LEDs
addressable-leds = []  # WS2811/WS2812 strip
status-led = []        # Single onboard LED
```

---

## SLCAN Protocol

Attachments use SLCAN (CAN-over-serial) for communication with bvrd.

### Commands

| Command | Description |
|---|---|
| `O\r` | Open CAN channel |
| `C\r` | Close CAN channel |
| `tIIILDD...\r` | Send standard frame |
| `V\r` | Query version |

### CAN Message IDs

| ID | Direction | Purpose |
|----|---|---|
| 0x200 | A→H | Heartbeat (1Hz) |
| 0x201 | H→A | Identify request |
| 0x202 | A→H | Identity response |
| 0x203 | H→A | Command |
| 0x204 | A→H | Acknowledgment |

A = Attachment, H = Host (bvrd)

### Example Session

```bash
# Open channel (starts heartbeat)
echo -ne "O\r" > /dev/ttyUSB0

# Request identity
echo -ne "t2010\r" > /dev/ttyUSB0

# Set LED to red (cmd=0x10, r=255, g=0, b=0)
echo -ne "t20341000FF0000\r" > /dev/ttyUSB0

# Close channel
echo -ne "C\r" > /dev/ttyUSB0
```

---

## Text Commands (Debug)

When connected via serial terminal:

| Command | Description |
|---|---|
| `led r,g,b` | Set LED color |
| `led off` | Turn off LEDs |
| `cycle` | Rainbow cycle mode |
| `state idle\|running\|error` | Set state |
| `rgb\|grb\|bgr` | Set color order |
| `ws2811\|ws2812` | Set timing |
| `help` | Show commands |

---

## Troubleshooting

### "No serial ports detected"

```bash
# Check if another process has the port
lsof /dev/cu.usbserial-*
killall screen
```

### "efuse blk rev" error

Use the included bootloader:
```bash
--bootloader bootloader.bin
```

### Binary won't boot

Check entry point:
```bash
xtensa-esp32s3-elf-readelf -h target/xtensa-esp32s3-none-elf/release/mcu-esp32s3
# Entry should be ~0x40378xxx, not 0x0
```

If 0x0, check `.cargo/config.toml` has:
```toml
rustflags = ["-C", "link-arg=-Wl,-Tlinkall.x"]
```

### LEDs not responding

- WS2811 (12V) requires level shifter (3.3V → 5V)
- Check GND connection between ESP32 and LED strip
- Try different color order: `grb`, `rgb`, `bgr`

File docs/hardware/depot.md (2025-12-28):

# Depot Rack

The depot is the base station for fleet operations. It houses the control
server, RTK base station, and operator display in a compact 10" mini rack.

## Overview

```
┌─────────────────────────────────────────────────────────────────────────────┐
│                              Depot Rack (10")                                │
│                                                                              │
│  ┌─────────────────────────────────────────────────────────────────────┐   │
│  │                          3U Touchscreen                             │   │
│  │                    Grafana / Operator / Fleet Map                   │   │
│  └─────────────────────────────────────────────────────────────────────┘   │
│  ┌─────────────────────────────────────────────────────────────────────┐   │
│  │  1U  │  PoE Switch (USW-Flex) ◄── DC from Power Station            │   │
│  └─────────────────────────────────────────────────────────────────────┘   │
│  ┌─────────────────────────────────────────────────────────────────────┐   │
│  │  1U  │  Raspberry Pi 5 + P31 HAT ◄── PoE (native)                  │   │
│  └─────────────────────────────────────────────────────────────────────┘   │
│  ┌─────────────────────────────────────────────────────────────────────┐   │
│  │  1U  │  RTK GPS (ZED-F9P) + USB Hub                                 │   │
│  └─────────────────────────────────────────────────────────────────────┘   │
│  ┌─────────────────────────────────────────────────────────────────────┐   │
│  │  1U  │  Patch Panel / Cable Management                              │   │
│  └─────────────────────────────────────────────────────────────────────┘   │
│                                                                              │
│                   External: Power Station + GNSS Antenna                     │
└─────────────────────────────────────────────────────────────────────────────┘
```

## Architecture

The depot uses PoE for internal power distribution. A single DC input from an
external power station feeds the PoE switch, which distributes power to all
rack components. The Raspberry Pi 5 with GeeekPi P31 HAT supports native PoE+,
eliminating the need for splitters on the compute side.

The mesh base station (Rocket 5AC) uses a separate 24V PoE injector (included).

```
Power Station (external)
    │
    │ 12V DC (or AC → adapter)
    ▼
┌─────────────────────────────────────────────────┐
│ PoE Switch (USW-Flex)                           │
│   ├── Port 1: Uplink (router/internet)          │
│   ├── Port 2: PoE+ ─► RPi5 + P31 HAT            │
│   ├── Port 3: PoE ──► Display (via splitter)    │
│   ├── Port 4: PoE ──► UniFi AP (Patron WiFi)    │
│   └── Port 5: (spare)                           │
└─────────────────────────────────────────────────┘
         │
         USB
         ▼
    ZED-F9P (RTK)
         │
         SMA cable (to roof)
         ▼
    GNSS Antenna

Separate: Mesh Base Station
─────────────────────────────
Power ──► [24V PoE Injector] ──► Rocket 5AC Prism ──► Omni Antenna
             (included)                                    │
                                                     airMAX mesh
                                                     to rovers
```

## Bill of Materials

### Rack Components

| U | Component | Model | Price | Notes |
| --- | --- | --- | ----- | --- |
| — | Rack | GeeekPi 10" 6U Open Frame | $80 | Wall or desk mount |
| 3U  | Display | GeeekPi 10.1" IPS Touchscreen | $110  | 1024×600, HDMI |
| 1U  | PoE Switch | Ubiquiti USW-Flex | $100  | 5-port, 46W PoE budget |
| 1U  | Shelf | 10" rack shelf | $15 | For RTK + USB hub |
| 1U  | Patch Panel  | 10" CAT6 6-port | $25 | Cable management |
| | **Subtotal** | | $330  | |

### Compute (Raspberry Pi 5)

| Component | Model | Price | Notes |
| --- | --- | ----- | --- |
| SBC | Raspberry Pi 5 8GB | $80 | ARM64, runs Docker |
| HAT | GeeekPi P31 NVMe PoE+ | $35 | PoE+ 802.3at, NVMe 2230/2242, fan |
| SSD | WD SN740 2230 256GB | $30 | Reliable, plenty for sessions |
| | **Subtotal** | $145  | |

The GeeekPi P31 HAT provides:

- Native PoE+ power (no splitter needed)
- M.2 NVMe slot (2230/2242)
- Active cooling with official fan

#### Alternative: x86 Compute

For more headroom or x86 compatibility:

| Component | Model | Price | Notes |
| --- | --- | ----- | --- |
| Mini PC | Beelink EQ12 | $200  | N100, 16GB, 500GB NVMe |
| Splitter  | PoE to 12V | $18 | 802.3at for PoE power  |
| | **Subtotal** | $218  | +$73 vs RPi5 |

### PoE Splitters

| Device  | Model | Output  | Price | Notes |
| --- | --- | --- | ----- | --- |
| Display | UCTRONICS PoE to micro-USB | 5V 2.5A | $12 | 802.3af |
| | **Subtotal** | | $12 | |

### RTK Base Station

| Component | Model | Price | Notes |
| --- | --- | ----- | --- |
| GPS Board | SparkFun GPS-RTK2 ZED-F9P | $275  | USB-C to compute |
| Antenna | Tallysman TW4721 | $100  | Survey-grade, roof mount |
| Cable | LMR-400 25ft + SMA | $50 | Low-loss for roof run |
| Mount | Magnetic or pole mount | $20 | Secure roof mounting |
| | **Subtotal** | $445  | |

### External Power

| Component | Model | Price | Notes |
| --- | --- | ----- | --- |
| Power Station | EcoFlow River 3 | $200  | 245Wh, solar-ready |
| DC Cable | 12V barrel to PoE | $10 | Or use AC outlet |
| | **Subtotal** | $210  | |

### Total Cost

| Category | Cost |
| --- | --- |
| Rack components  | $330 |
| Compute (RPi5) | $145 |
| PoE splitters | $12 |
| RTK base station | $445 |
| External power | $210 |
| **Total** | ~$1,140 |

## Software Stack

The depot runs Docker services on the Raspberry Pi 5:

| Service | Port | Purpose |
| --- | ---- | --- |
| Discovery | 4860 | Rover registration/discovery |
| Operator  | 8080 | Web-based teleop interface |
| InfluxDB  | 8086 | Time-series metrics storage  |
| Grafana | 3000 | Fleet dashboards |
| SFTP | 2222 | Session file uploads |
| NTRIP | 2101 | RTK corrections broadcast |

See [depot/README.md](../../depot/README.md) for setup instructions.

## Power Budget

| Component  | Power | Notes |
| --- | --- | --- |
| RPi5 + P31 | 5-12W | Idle vs full load |
| Display | 5W | Backlight at 50% |
| PoE Switch | 3W | Self-consumption |
| ZED-F9P | 0.5W | USB-powered |
| UniFi AP | 6-10W | Optional, for patron WiFi |
| **Total**  | ~15-32W | With optional AP |

### Internet Gateway

The depot requires a router/gateway for internet access, NAT, and DHCP. Options:

| Option | Device | Notes |
| --- | --- | --- |
| ISP-provided | Starlink router, AT&T gateway | Simplest, included with service |
| Dedicated | UniFi Dream Router ($199) | Full control, UniFi ecosystem |
| RPi5 | Configure as gateway | No extra hardware, more complex |

The USW-Flex is a Layer 2 switch only; it cannot route or provide DHCP.

```
Internet ──► [ISP Router/Gateway] ──► USW-Flex ──► Rack devices
                    │
              NAT, DHCP, Firewall
```

### Mesh Base Station (Separate Power)

The Rocket 5AC Prism uses Ubiquiti's proprietary 24V passive PoE, not standard
802.3af/at. The USW-Flex outputs 48V PoE which is incompatible. Use the
included 24V PoE injector:

| Component | Power | Notes |
| --- | ----- | --- |
| Rocket 5AC Prism | 8W | Separate 24V PoE injector |

### USW-Flex Port Allocation

| Port | Device | PoE Power | Notes |
| ---- | --- | --- | --- |
| 1 | Uplink (router) | - | Non-PoE |
| 2 | RPi5 + P31 HAT  | ~12W | PoE+ |
| 3 | Display | ~5W | Via splitter |
| 4 | UniFi AP | ~10W | Patron WiFi  |
| 5 | (Spare) | - | Future use |

Total PoE budget: 46W available, ~27W used.

With the EcoFlow River 3 (245Wh), expect:

- **~11-16 hours** at typical load
- **Indefinite** with 100W solar panel attached

## Assembly

### 1. Rack Setup

1. Assemble 10" rack frame
2. Mount to wall or set on desk
3. Install 10" shelf and patch panel

### 2. Compute Installation

1. Attach GeeekPi P31 HAT to Raspberry Pi 5
2. Install WD SN740 NVMe SSD in M.2 slot
3. Mount Pi + HAT assembly on rack shelf
4. Connect single ethernet cable (provides power + network)
5. Connect HDMI to display
6. Connect USB: ZED-F9P, optional peripherals

### 3. Networking

1. Mount PoE switch in 1U slot
2. Run ethernet from PoE switch to:
   - Port 1: Uplink (router/internet)
   - Port 2: RPi5 (native PoE+ via P31 HAT)
   - Port 3: Display (via PoE splitter)
   - Port 4: UniFi AP (optional, for patron WiFi)
3. Connect power station to PoE switch
4. Set up Rocket 5AC with its own 24V PoE injector (separate from rack)

### 4. RTK Base Station

1. Mount GNSS antenna on roof with clear sky view
2. Run LMR-400 cable from antenna to rack
3. Connect antenna to ZED-F9P via SMA
4. Connect ZED-F9P to compute via USB
5. Configure for base station mode (see [rtk.md](rtk.md))

### 5. Software

```bash
cd depot
docker compose up -d
```

Access Grafana at `http://localhost:3000` to verify services.

## Network Ports

| Port | Protocol | Service | Purpose |
| ---- | --- | --- | --- |
| 2101 | TCP | NTRIP | RTK corrections |
| 2222 | TCP | SFTP | Session uploads |
| 3000 | TCP | Grafana | Fleet dashboards |
| 4860 | TCP | Discovery | Rover registration |
| 8080 | TCP | Operator  | Web teleop |
| 8086 | TCP | InfluxDB  | Metrics API |
| 8089 | UDP | InfluxDB  | Metrics push |

## Field Deployment

For temporary or field deployments:

1. Charge power station fully
2. Set up rack (desk or wall mount)
3. Deploy GNSS antenna with temporary tripod
4. Connect to rovers via LTE or local WiFi
5. Monitor via touchscreen

The compact form factor fits in a vehicle for mobile base operations.

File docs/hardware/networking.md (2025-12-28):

# Rover Networking

Network architecture for BVR rovers and depot communication.

## Overview

BVR uses a **Ubiquiti mesh network** for low-latency rover communication.
This eliminates LTE data costs and provides 5-50ms latency (vs 100-250ms with LTE).

```
┌─────────────────────────────────────────────────────────────────────────────┐
│                              Depot                                           │
│                                                                              │
│  ┌─────────────┐    ┌─────────────┐    ┌─────────────────────────────────┐ │
│  │ Operator    │    │ InfluxDB    │    │ Rocket 5AC Prism                │ │
│  │ Station     │    │ SFTP, etc.  │    │ + Omni Antenna                  │ │
│  └──────┬──────┘    └──────┬──────┘    └───────────────┬─────────────────┘ │
│         └──────────────────┴───────────────────────────┘                    │
│                                         │ Ethernet                          │
└─────────────────────────────────────────┼───────────────────────────────────┘
                                          │
                         5 GHz Mesh (PtMP + rover-to-rover relay)
                                          │
          ┌───────────────────────────────┼───────────────────────────────┐
          │                               │                               │
          ▼                               ▼                               ▼
   ┌────────────┐                  ┌────────────┐                  ┌────────────┐
   │ Rover A    │ ◄──── mesh ────► │ Rover B    │ ◄──── mesh ────► │ Rover C    │
   │ NanoStation│                  │ NanoStation│                  │ NanoStation│
   └────────────┘                  └────────────┘                  └────────────┘

Optional: Fixed repeaters added where coverage gaps are identified
```

## Network Strategy: Mesh-First, Repeaters Where Needed

**Phase 1: Mesh Only**

- Deploy with depot base station + rover radios only
- Rovers relay for each other when out of direct range
- Mesh health metrics identify coverage gaps

**Phase 2: Data-Driven Repeaters**

- Analyze mesh metrics (RSSI, latency, hop count) from InfluxDB
- Add fixed repeaters only at specific problem locations
- Typical cost: $200-250 per repeater site

This approach minimizes upfront infrastructure while ensuring coverage grows with demand.

## Patron WiFi (Optional)

The depot mesh infrastructure can double as community WiFi, providing value to
the neighborhood and leverage for repeater placement negotiations.

### Requirements

- **ISP with redistribution rights**: AT&T Business (patron WiFi allowed) or
  Starlink Priority ($165+/mo, explicitly permits community hotspots)
- **Additional hardware**: UniFi AP at depot and/or repeater sites (~$99-180 each)
- **QoS configuration**: Prioritize rover traffic over public WiFi
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

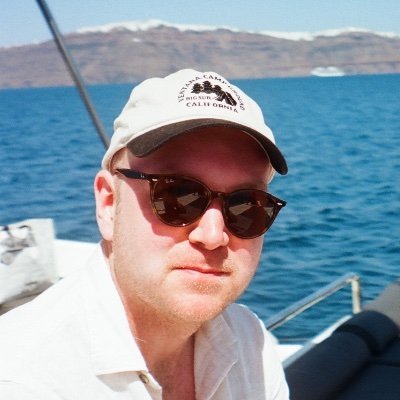
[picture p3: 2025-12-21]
web/public/images/cam.png

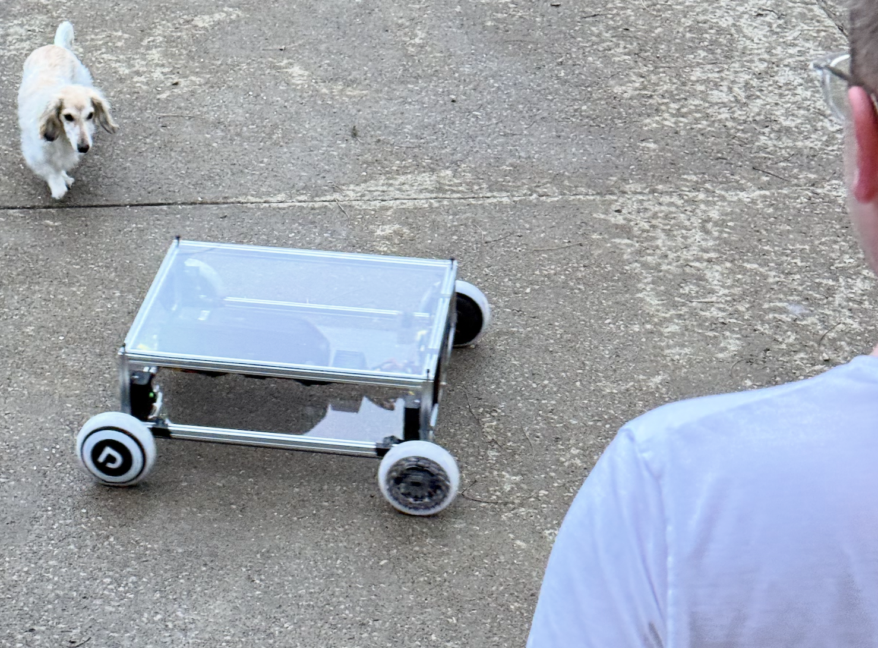
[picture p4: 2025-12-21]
web/public/images/bvr0.png

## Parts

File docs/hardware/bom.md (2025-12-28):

# Bill of Materials

## Summary

| Category | Est. Cost |
| --- | --- |
| Chassis | $150 |
| Drivetrain  | $800 |
| Electronics | $1,286 |
| Perception  | $1,800 |
| Power | $400 |
| Wiring/Misc | $100 |
| **Total** | **~$4,536** |

Depot base station adds ~$1,540 (rack + mesh). Fixed repeaters: $114-214 each as needed.

## Detailed BOM

### Chassis

| Part | Qty | Unit  | Total | Link |
| --- | --- | ----- | --- | --- |
| 2020 extrusion 600mm | 8 | $5 | $40 | |
| 2020 corner bracket | 16  | $2 | $32 | |
| M5×10 BHCS | 100 | $0.10 | $10 | |
| M5 T-nut | 100 | $0.15 | $15 | |
| Electronics plate (1/4" AL) | 1 | $50 | $50 | SendCutSend |
| **Subtotal** | | | **$147** | |

### Drivetrain

| Part | Qty | Unit | Total | Link |
| --- | --- | ---- | --- | --- |
| Hoverboard hub motor 350W | 4 | $50  | $200 | AliExpress  |
| VESC 6.6 | 4 | $120 | $480 | Flipsky |
| Motor mount (custom) | 4 | $20  | $80 | SendCutSend |
| Wheel spacer (custom) | 4 | $10  | $40 | SendCutSend |
| **Subtotal** | | | **$800** | |

### Electronics

| Part | Qty | Unit | Total | Link |
| --- | --- | ---- | --- | --- |
| Jetson Orin NX 16GB | 1 | $600 | $600 | NVIDIA |
| Jetson carrier board | 1 | $100 | $100 | Seeed |
| USB CAN adapter | 1 | $30  | $30 | Amazon |
| Proxicast 7-in-1 combo | 1 | $367 | $367 | Amazon |
| Bullet AC IP67 | 1 | $129 | $129 | UI Store |
| RP-SMA to N adapter | 1 | $10  | $10 | Amazon |
| 7" HDMI display | 1 | $50  | $50 | Amazon |
| **Subtotal** | | | **$1,286** | |

Note: Proxicast 7-in-1 includes GPS and 4x4 MIMO 5G antenna ports for LTE/5G
fallback. See [networking.md](networking.md).

### Perception

| Part | Qty | Unit | Total | Link |
| --- | --- | --- | --- | --- |
| Livox Mid-360 LiDAR | 1 | $1,500 | $1,500 | Livox / DJI |
| Insta360 X4 | 1 | $300 | $300 | Amazon |
| Sensor mount pole (1" AL) | 1 | $20 | $20 | Amazon |
| **Subtotal** | | | **$1,820** | |

See [sensors.md](sensors.md) for detailed specifications and integration.

### Power System

| Part | Qty | Unit | Total | Link |
| --- | --- | ---- | --- | --- |
| 13S4P battery pack 20Ah | 1 | $300 | $300 | Custom |
| 48V→12V DCDC 20A | 1 | $40  | $40 | Amazon |
| 100A ANL fuse + holder  | 1 | $15  | $15 | Amazon |
| E-Stop relay 100A | 1 | $25  | $25 | Amazon |
| E-Stop button | 1 | $15  | $15 | Amazon |
| **Subtotal** | | | **$395** | |

### Wiring & Connectors

| Part | Qty | Unit | Total | Link |
| --- | --- | ---- | --- | --- |
| 8 AWG silicone wire (red) | 2m  | $3/m | $6 | Amazon |
| 8 AWG silicone wire (black) | 2m  | $3/m | $6 | Amazon |
| 14 AWG wire assortment | 1 | $15  | $15 | Amazon |
| 22 AWG twisted pair | 5m  | $1/m | $5 | Amazon |
| XT90 connectors (5 pair) | 1 | $12  | $12 | Amazon |
| XT30 connectors (10 pair) | 1 | $8 | $8 | Amazon |
| Deutsch DT connector kit | 1 | $25  | $25 | Amazon |
| Heat shrink kit | 1 | $12  | $12 | Amazon |
| Cable management | 1 | $10  | $10 | Amazon |
| **Subtotal** | | | **$99** | |

## Tool: Snow Auger

| Part | Qty | Unit | Total | Link |
| --- | --- | ---- | --- | --- |
| RP2040 Pico W | 1 | $8 | $8 | |
| MCP2515 CAN module  | 1 | $5 | $5 | |
| Linear actuator 12" | 1 | $60  | $60 | Amazon |
| Auger motor 500W | 1 | $80  | $80 | |
| Motor controller | 1 | $30  | $30 | |
| Auger assembly | 1 | $150 | $150 | |
| Mount hardware | 1 | $30  | $30 | |
| **Subtotal** | | | **$363** | |

## bvr1 Optional Upgrades

These components are not required for bvr0 but enable enhanced capabilities.

### RTK GPS (Per Rover)

For centimeter-accurate georeferenced mapping. Same hardware as depot base
station, configured in rover mode.

| Part | Qty | Unit | Total | Link |
| --- | --- | ---- | --- | --- |
| SparkFun GPS-RTK2 (ZED-F9P) | 1 | $275 | $275 | [Amazon](https://www.amazon.com/SparkFun-GPS-RTK2-Board-ZED-F9P-Qwiic/dp/B07NBPNWNZ) |
| GNSS Multi-Band Antenna | 1 | $80  | $80 | SparkFun |
| SMA cable (1m) | 1 | $15  | $15 | Amazon |
| **Subtotal** | | | **$370** | |

See [rover-rack.md](rover-rack.md) for mounting and [rtk.md](rtk.md) for setup.

### Network Switch (Per Rover)

For debug access and future sensor expansion.

| Part | Qty | Unit | Total | Link |
| --- | --- | ---- | --- | --- |
| Netgear GS305 (5-port gigabit) | 1 | $20  | $20 | Amazon |
| Ethernet cables (0.5m) | 3 | $3 | $9 | Amazon |
| **Subtotal** | | | **$29** | |

### Hardware-Synced Camera (Per Rover)

For high-quality Gaussian splatting (replaces Insta360).

| Part | Qty | Unit | Total | Link |
| --- | --- | ---- | --- | --- |
| FLIR Blackfly S (global shutter) | 2 | $500 | $1,000 | B&H |
| Wide-angle lens (CS mount) | 2 | $50  | $100 | Amazon |
| Sync cable (Mid-360 PPS) | 1 | $20  | $20 | Custom |
| **Subtotal** | | | **$1,120** | |

## Depot Rack

Complete base station for fleet operations. See [depot.md](depot.md) for full details.

| Part | Qty | Unit | Total | Link |
| --- | --- | ---- | --- | --- |
| GeeekPi 10" 6U Rack | 1 | $80  | $80 | Amazon |
| GeeekPi 10.1" Touchscreen | 1 | $110 | $110 | Amazon |
| Ubiquiti USW-Flex PoE | 1 | $100 | $100 | UI Store  |
| Raspberry Pi 5 8GB | 1 | $80  | $80 | PiShop |
| GeeekPi P31 NVMe PoE+ HAT | 1 | $35  | $35 | Amazon |
| WD SN740 2230 256GB | 1 | $30  | $30 | Amazon |
| SparkFun GPS-RTK2 (ZED-F9P) | 1 | $275 | $275 | Amazon |
| Tallysman TW4721 antenna | 1 | $100 | $100 | Tallysman |
| LMR-400 cable (25ft) | 1 | $50  | $50 | Amazon |
| EcoFlow River 3 | 1 | $200 | $200 | Amazon |
| Misc (shelf, splitter, etc) | 1 | $80  | $80 | Various |
| **Subtotal** | | | **$1,140** | |

Note: Requires internet gateway (ISP-provided router, or add UniFi Dream Router
for $199). The USW-Flex is Layer 2 only and cannot provide NAT/DHCP.

### Mesh Base Station (Required)

| Part | Qty | Unit | Total | Link |
| --- | --- | ---- | --- | --- |
| Rocket 5AC Prism | 1 | $249 | $249 | UI Store |
| AMO-5G13 omni antenna | 1 | $130 | $130 | UI Store |
| Antenna mount + cable | 1 | $50  | $50 | Amazon |
| **Subtotal** | | | **$429** | |

Note: Omni provides 360° coverage for rovers dispatching in all directions.
Sector (AM-5G17-90, $100) available if longer range in one direction is needed.

### Patron WiFi (Optional)

| Part | Qty | Unit | Total | Link |
| --- | --- | ---- | --- | --- |
| UniFi AP AC Lite | 1 | $99  | $99 | UI Store |
| **Subtotal** | | | **$99** | |

Provides public WiFi at depot. Requires ISP with redistribution rights (AT&T
Business or Starlink Priority). See [networking.md](networking.md) for details.

### Fixed Repeater (Optional, add where needed)

| Part | Qty | Unit | Total | Link |
| --- | --- | ---- | --- | --- |
| NanoStation 5AC Loco | 1 | $49  | $49 | UI Store |
| Outdoor NEMA enclosure | 1 | $30  | $30 | Amazon |
| PoE injector 24V | 1 | $15  | $15 | UI Store |
| Pole mount clamps | 1 | $20  | $20 | Amazon |
| Solar kit (if no grid) | 1 | $100 | $100 | Amazon |
| **Subtotal (grid power)** | | | **$114** | |
| **Subtotal (solar)** | | | **$214** | |

Alternatively, use an NTRIP network subscription (~$50/month) instead of
running your own RTK base station.

See [depot.md](depot.md) for rack setup and [rtk.md](rtk.md) for RTK configuration.

## Vendor Notes

- **SendCutSend**: Custom cut aluminum/steel, fast turnaround
- **Flipsky**: VESC clones, good value
- **AliExpress**: Hoverboard motors (2-3 week shipping)
- **Seeed Studio**: Jetson carrier boards
- **Livox/DJI**: Mid-360 LiDAR (direct order, ~1 week)
- **Amazon**: Insta360, mounting hardware (Prime shipping)
- **SparkFun**: GPS-RTK2, GNSS antennas

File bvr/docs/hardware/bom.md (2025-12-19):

# Bill of Materials

## Summary

| Category | Est. Cost |
| --- | --- |
| Chassis | $150 |
| Drivetrain  | $800 |
| Electronics | $900 |
| Perception  | $1,800 |
| Power | $400 |
| Wiring/Misc | $100 |
| **Total** | **~$4,150** |

## Detailed BOM

### Chassis

| Part | Qty | Unit  | Total | Link |
| --- | --- | ----- | --- | --- |
| 2020 extrusion 600mm | 8 | $5 | $40 | |
| 2020 corner bracket | 16  | $2 | $32 | |
| M5×10 BHCS | 100 | $0.10 | $10 | |
| M5 T-nut | 100 | $0.15 | $15 | |
| Electronics plate (1/4" AL) | 1 | $50 | $50 | SendCutSend |
| **Subtotal** | | | **$147** | |

### Drivetrain

| Part | Qty | Unit | Total | Link |
| --- | --- | ---- | --- | --- |
| Hoverboard hub motor 350W | 4 | $50  | $200 | AliExpress  |
| VESC 6.6 | 4 | $120 | $480 | Flipsky |
| Motor mount (custom) | 4 | $20  | $80 | SendCutSend |
| Wheel spacer (custom) | 4 | $10  | $40 | SendCutSend |
| **Subtotal** | | | **$800** | |

### Electronics

| Part | Qty | Unit | Total | Link |
| --- | --- | ---- | --- | --- |
| Jetson Orin NX 16GB | 1 | $600 | $600 | NVIDIA |
| Jetson carrier board | 1 | $100 | $100 | Seeed  |
| USB CAN adapter | 1 | $30  | $30 | Amazon |
| LTE modem (Sierra MC7455) | 1 | $80  | $80 | eBay |
| 7" HDMI display | 1 | $50  | $50 | Amazon |
| GPS module (optional) | 1 | $30  | $30 | Amazon |
| **Subtotal** | | | **$890** | |

### Perception

| Part | Qty | Unit | Total | Link |
| --- | --- | --- | --- | --- |
| Livox Mid-360 LiDAR | 1 | $1,500 | $1,500 | Livox / DJI |
| Insta360 X4 | 1 | $300 | $300 | Amazon |
| Sensor mount pole (1" AL) | 1 | $20 | $20 | Amazon |
| **Subtotal** | | | **$1,820** | |

See [sensors.md](sensors.md) for detailed specifications and integration.

### Power System

| Part | Qty | Unit | Total | Link |
| --- | --- | ---- | --- | --- |
| 13S4P battery pack 20Ah | 1 | $300 | $300 | Custom |
| 48V→12V DCDC 20A | 1 | $40  | $40 | Amazon |
| 100A ANL fuse + holder  | 1 | $15  | $15 | Amazon |
| E-Stop relay 100A | 1 | $25  | $25 | Amazon |
| E-Stop button | 1 | $15  | $15 | Amazon |
| **Subtotal** | | | **$395** | |

### Wiring & Connectors

| Part | Qty | Unit | Total | Link |
| --- | --- | ---- | --- | --- |
| 8 AWG silicone wire (red) | 2m  | $3/m | $6 | Amazon |
| 8 AWG silicone wire (black) | 2m  | $3/m | $6 | Amazon |
| 14 AWG wire assortment | 1 | $15  | $15 | Amazon |
| 22 AWG twisted pair | 5m  | $1/m | $5 | Amazon |
| XT90 connectors (5 pair) | 1 | $12  | $12 | Amazon |
| XT30 connectors (10 pair) | 1 | $8 | $8 | Amazon |
| Deutsch DT connector kit | 1 | $25  | $25 | Amazon |
| Heat shrink kit | 1 | $12  | $12 | Amazon |
| Cable management | 1 | $10  | $10 | Amazon |
| **Subtotal** | | | **$99** | |

## Tool: Snow Auger

| Part | Qty | Unit | Total | Link |
| --- | --- | ---- | --- | --- |
| RP2040 Pico W | 1 | $8 | $8 | |
| MCP2515 CAN module  | 1 | $5 | $5 | |
| Linear actuator 12" | 1 | $60  | $60 | Amazon |
| Auger motor 500W | 1 | $80  | $80 | |
| Motor controller | 1 | $30  | $30 | |
| Auger assembly | 1 | $150 | $150 | |
| Mount hardware | 1 | $30  | $30 | |
| **Subtotal** | | | **$363** | |

## bvr1 Optional Upgrades

These components are not required for bvr0 but enable enhanced capabilities.

### RTK GPS (Per Rover)

For centimeter-accurate georeferenced mapping.

| Part | Qty | Unit | Total | Link |
| --- | --- | ---- | --- | --- |
| SparkFun GPS-RTK2 (ZED-F9P) | 1 | $220 | $220 | [Amazon](https://www.amazon.com/SparkFun-GPS-RTK2-Board-ZED-F9P-Qwiic/dp/B07NBPNWNZ) |
| GNSS Multi-Band Antenna | 1 | $75  | $75 | SparkFun |
| SMA cable (1m) | 1 | $10  | $10 | Amazon |
| **Subtotal** | | | **$305** | |

### Network Switch (Per Rover)

For debug access and future sensor expansion.

| Part | Qty | Unit | Total | Link |
| --- | --- | ---- | --- | --- |
| Netgear GS305 (5-port gigabit) | 1 | $20  | $20 | Amazon |
| Ethernet cables (0.5m) | 3 | $3 | $9 | Amazon |
| **Subtotal** | | | **$29** | |

### Hardware-Synced Camera (Per Rover)

For high-quality Gaussian splatting (replaces Insta360).

| Part | Qty | Unit | Total | Link |
| --- | --- | ---- | --- | --- |
| FLIR Blackfly S (global shutter) | 2 | $500 | $1,000 | B&H |
| Wide-angle lens (CS mount) | 2 | $50  | $100 | Amazon |
| Sync cable (Mid-360 PPS) | 1 | $20  | $20 | Custom |
| **Subtotal** | | | **$1,120** | |

## Depot: RTK Base Station

For broadcasting RTK corrections to the fleet.

| Part | Qty | Unit | Total | Link |
| --- | --- | ---- | --- | --- |
| SparkFun GPS-RTK2 (ZED-F9P) | 1 | $220 | $220 | Amazon |
| Tallysman TW4721 antenna | 1 | $100 | $100 | Tallysman |
| LMR-400 cable (25ft) | 1 | $40  | $40 | Amazon |
| Antenna roof mount | 1 | $20  | $20 | Amazon |
| USB extension (if needed) | 1 | $10  | $10 | Amazon |
| **Subtotal** | | | **$390** | |

Alternatively, use an NTRIP network subscription (~$50/month) instead of
running your own base station.

See [rtk.md](rtk.md) for setup instructions.

## Vendor Notes

- **SendCutSend**: Custom cut aluminum/steel, fast turnaround
- **Flipsky**: VESC clones, good value
- **AliExpress**: Hoverboard motors (2-3 week shipping)
- **Seeed Studio**: Jetson carrier boards
- **Livox/DJI**: Mid-360 LiDAR (direct order, ~1 week)
- **Amazon**: Insta360, mounting hardware (Prime shipping)
- **SparkFun**: GPS-RTK2, GNSS antennas

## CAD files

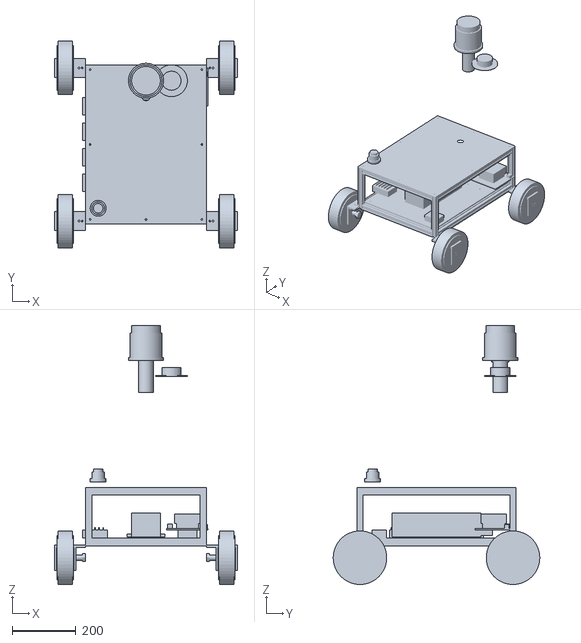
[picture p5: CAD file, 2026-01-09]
web/public/models/bvr1_assembly.stl
574.0 x 648.0 x 812.1

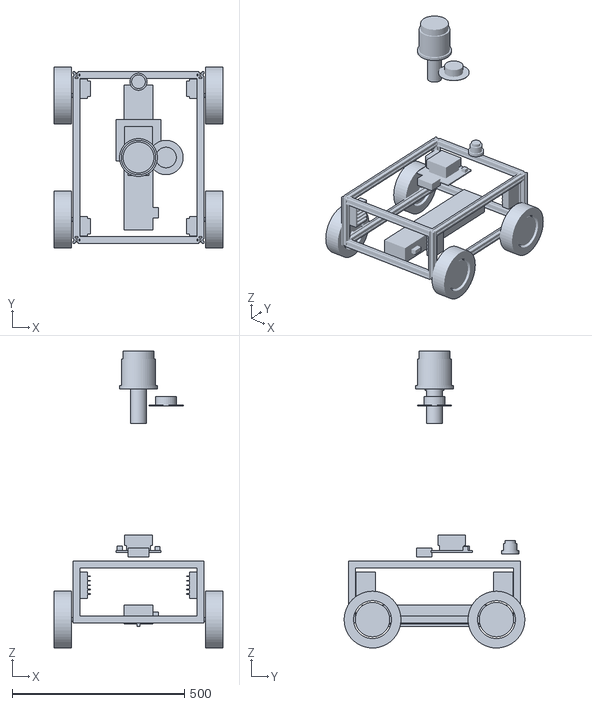
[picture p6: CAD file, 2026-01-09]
web/public/models/bvr0_assembly.stl
490.0 x 525.0 x 862.6

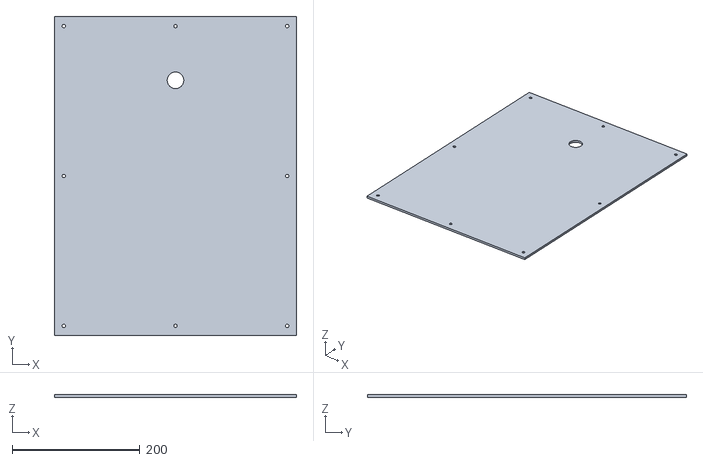
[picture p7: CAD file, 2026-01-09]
web/public/models/access_panel.stl
380.0 x 500.0 x 4.00

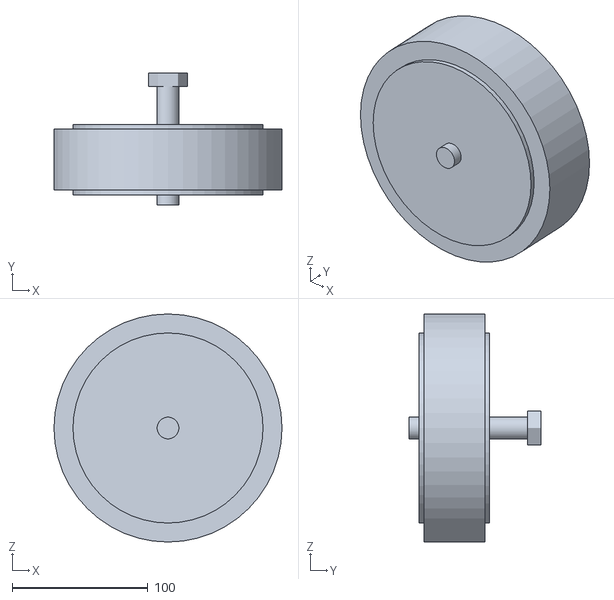
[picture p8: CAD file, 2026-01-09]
web/public/models/uumotor_svb6hs.stl
168.0 x 97.5 x 168.0

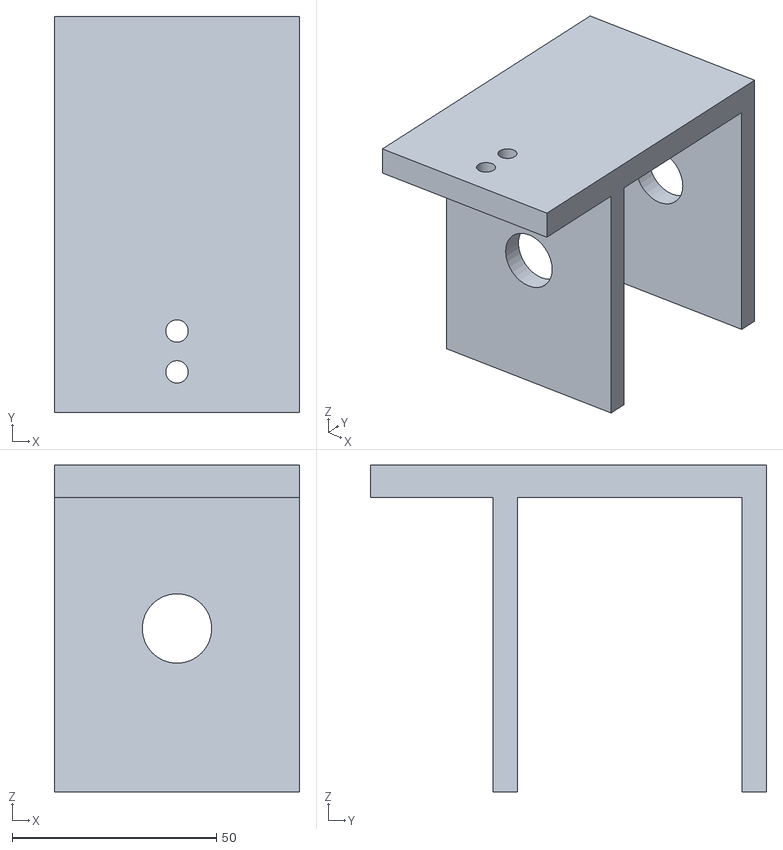
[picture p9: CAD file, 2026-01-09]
web/public/models/uumotor_mount.stl
60.0 x 97.0 x 80.0

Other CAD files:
bvr/cad/exports/stl/bvr1_assembly.stl
bvr/cad/exports/stl/bvr0_assembly.stl
bvr/cad/bvr1_frame.stl
bvr/cad/exports/corner_bracket.stl
bvr/cad/exports/stl/blower_nozzle.3mf
bvr/cad/exports/extrusion_2020_100mm.stl
bvr/cad/rail.stl
bvr/cad/exports/ref_vesc_6.stl
bvr/cad/exports/stl/ref_lidar_mid360.stl
bvr/cad/KN6104.dwg
bvr/cad/exports/access_panel.stl
bvr/cad/exports/stl/ref_proxicast_antenna.stl
bvr/cad/exports/ref_estop.stl
bvr/cad/exports/base_tray.stl
bvr/cad/exports/battery_tray.stl
bvr/cad/exports/bvr0_assembly.stl
bvr/cad/exports/bvr1_assembly.stl
bvr/cad/exports/bvr1_frame.stl
bvr/cad/exports/dxf/shell_top_lid.dxf
bvr/cad/exports/dxf/shell_wall_wrap.dxf
bvr/cad/exports/electronics_plate.stl
bvr/cad/exports/electronics_plate_simple.stl
bvr/cad/exports/extrusion_2020_500mm.stl
bvr/cad/exports/motor_mount_8in.stl
bvr/cad/exports/motor_mount_plate_8in.stl
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

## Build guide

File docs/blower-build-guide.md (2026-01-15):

# Blower System Assembly Guide

**Purpose:** Debris-clearing tool for autonomous rover demonstration
**Timeline:** Week 4 (2 days assembly + testing)
**Skill Level Required:** Basic mechanical assembly, soldering, electrical connections
**Estimated Total Time:** 8-10 hours (excluding 3D printing time)

---

## Table of Contents

1. [Pre-Assembly Checklist](#pre-assembly-checklist)
2. [Mechanical Assembly (Day 1)](#mechanical-assembly-day-1)
3. [Shell Integration (Day 2 Morning)](#shell-integration-day-2-morning)
4. [Electrical Integration (Day 2 Afternoon)](#electrical-integration-day-2-afternoon)
5. [Bench Testing](#bench-testing)
6. [Debris Testing](#debris-testing)
7. [Troubleshooting](#troubleshooting)

---

## Pre-Assembly Checklist

### Parts List

**Electronics:**
- [ ] 90mm EDF unit (motor + impeller, pre-balanced)
- [ ] VESC 75/300 motor controller with CAN capability
- [ ] Conformal coating (MG Chemicals 422B or equivalent)
- [ ] Heat shrink tubing assortment
- [ ] Silicone wire: 14 AWG (1m red, 1m black)
- [ ] XT60 or XT90 connector pair (power connection)

**Mechanical:**
- [ ] 3D printed volute housing (ASA filament)
- [ ] 3D printed expansion nozzle (ASA filament)
- [ ] Aluminum shell from SendCutSend (powder-coated orange)
- [ ] Intake vent baffles (3D printed or machined)
- [ ] Drain grommets (6mm rubber, McMaster)

**Mounting Hardware:**
- [ ] M5×10mm button head screws (20x)
- [ ] M5×16mm button head screws (10x)
- [ ] M5 T-nuts for 2020 extrusion (20x)
- [ ] M4×8mm screws for motor mount (4x)
- [ ] M3×8mm screws for VESC mount (4x)
- [ ] Threadlocker (Loctite 243 blue)

**Consumables:**
- [ ] Isopropyl alcohol (cleaning)
- [ ] Shop towels
- [ ] Electrical tape
- [ ] Zip ties (assorted sizes)
- [ ] Cable lacing cord (optional, for clean routing)

### Tools Required

**Hand Tools:**
- [ ] Hex key set (1.5mm - 5mm)
- [ ] Screwdriver set (Phillips, flathead)
- [ ] Wire cutters/strippers
- [ ] Needle nose pliers
- [ ] Adjustable wrench
- [ ] Deburring tool or utility knife

**Power Tools:**
- [ ] Drill with bits (2.5mm, 3mm, 4mm)
- [ ] Soldering iron (60W recommended)
- [ ] Heat gun or lighter (for heat shrink)

**Test Equipment:**
- [ ] Multimeter
- [ ] Power supply or battery (48V, 10A minimum)
- [ ] Tachometer or laser tachometer (optional)
- [ ] Clamp meter (for current measurement)

**Safety Equipment:**
- [ ] Safety glasses
- [ ] Work gloves
- [ ] Hearing protection (for testing)
- [ ] Ventilation (for soldering/coating)

### Pre-Fabrication Requirements

Before starting assembly, ensure these items are ready:

1. **3D Printing Complete:**
   - Volute housing (print time: 20-30 hours)
   - Expansion nozzle sections (print time: 10-15 hours)
   - Intake vent baffles (print time: 2-4 hours)
   - All parts inspected, no warping or layer separation
   - Support material removed and cleaned up

2. **Shell Fabrication:**
   - Aluminum shell panels cut and bent by SendCutSend
   - Powder coating applied (orange, Muni standard)
   - Blower cutout integrated into shell design
   - Mounting holes for chassis attachment pre-drilled

3. **Workspace Setup:**
   - Clean, well-lit work area
   - ESD-safe mat (for electronics)
   - Parts organized in bins/trays
   - Access to compressed air (for cleaning)

---

## Mechanical Assembly (Day 1)

**Time Required:** 3-4 hours
**Goal:** Complete blower assembly ready for shell integration

### Step 1: Inspect Components (15 minutes)

1. **Unpack EDF unit carefully:**
   - Check motor shaft for damage
   - Verify impeller blades are intact and balanced
   - Inspect motor wires for fraying
   - Confirm mounting holes align with volute housing

2. **Inspect 3D printed parts:**
   - Check for warping (especially on large flat surfaces)
   - Remove any support material residue
   - Test-fit parts together before assembly
   - Sand any rough edges that could cause air leaks

3. **Verify hardware:**
   - Count all screws and T-nuts
   - Check for correct lengths
   - Ensure Loctite is not expired (shelf life ~2 years)

> **Photo Placeholder:** Laid-out components on workbench

### Step 2: Mount Motor to Volute Housing (30 minutes)

The volute housing is the heart of the blower system. Proper mounting ensures good airflow and minimal vibration.

1. **Prepare mounting surface:**
   - Clean volute motor mount face with isopropyl alcohol
   - Remove any print artifacts around screw holes
   - Check that motor mounting face is flat

2. **Apply Loctite to motor screws:**
   - Use **blue Loctite 243** only (removable)
   - Apply one small drop to each M4 screw thread
   - Do NOT use red Loctite (permanent)

3. **Align motor to volute:**
   - Motor output shaft should be centered in volute inlet
   - Motor wires should exit toward the rear (away from nozzle)
   - Use alignment marks on 3D print if present

4. **Torque screws in star pattern:**
   - Tighten opposite screws alternately
   - Final torque: snug + 1/4 turn (approximately 2-3 Nm)
   - Do NOT overtighten into plastic

5. **Verify alignment:**
   - Motor shaft should spin freely without rubbing
   - No visible wobble when spun by hand
   - Air gap around shaft should be even (±0.5mm)

> **Photo Placeholder:** Motor mounted to volute, showing alignment

### Step 3: Install Impeller (45 minutes)

**WARNING:** Impeller installation is critical for safety. An improperly secured impeller can cause catastrophic failure at high RPM.

1. **Inspect impeller and shaft:**
   - Clean both with isopropyl alcohol
   - Check for burrs or damage
   - Verify set screw hole is clean and threaded

2. **Slide impeller onto motor shaft:**
   - Align keyway if present
   - Push impeller fully onto shaft until it seats
   - Impeller should NOT contact volute housing walls

3. **Position impeller for optimal clearance:**
   - Measure gap between impeller and volute inlet (~2-3mm ideal)
   - Adjust position on shaft if needed
   - Mark shaft position with marker

4. **Apply Loctite to set screw:**
   - Use **blue Loctite 243**
   - Apply to set screw threads
   - Insert set screw into impeller hub

5. **Tighten set screw:**
   - Tighten until it contacts shaft flat (if present)
   - Final torque: snug + 1/8 turn
   - Do NOT overtighten (can strip aluminum hub)

6. **Balance check (critical):**
   - Spin impeller by hand (should coast smoothly)
   - No wobble or vibration when spinning
   - If vibration detected, loosen and re-align

7. **Let Loctite cure:**
   - Wait 10 minutes minimum before proceeding
   - Full cure: 24 hours (do not run at full power before then)

> **Photo Placeholder:** Impeller installed with proper clearance visible

### Step 4: Attach Expansion Nozzle (30 minutes)

The expansion nozzle transitions from the circular volute outlet to a wide slot for maximum coverage.

1. **Dry-fit nozzle to volute:**
   - Align mounting holes
   - Check that transition is smooth (no sharp steps)
   - Mark any areas that need trimming/sanding

2. **Sand mating surfaces if needed:**
   - Goal: airtight seal at junction
   - Use 220-grit sandpaper on high spots
   - Clean with compressed air

3. **Apply sealant (optional but recommended):**
   - Use silicone RTV sealant at nozzle-volute junction
   - Thin bead around perimeter
   - Prevents air leaks that reduce efficiency

4. **Bolt nozzle to volute:**
   - Use M5×10mm screws
   - Start all screws before tightening any
   - Tighten in star pattern
   - Final torque: snug (do not overtighten into plastic)

5. **Wipe excess sealant:**
   - Remove any sealant squeeze-out inside nozzle
   - Smooth with finger or tool
   - Let cure per manufacturer instructions (usually 24 hours)

6. **Measure nozzle outlet dimensions:**
   - Should be approximately 500mm wide × 50mm tall
   - Verify no obstructions in airflow path

> **Photo Placeholder:** Nozzle attached, showing smooth transition

### Step 5: Test-Fit in Shell (45 minutes)

Before final integration, ensure the blower assembly fits properly in the shell.

1. **Position shell on workbench:**
   - Place shell upside-down or on side for access
   - Ensure it's stable and won't roll

2. **Insert blower assembly into shell cutout:**
   - Nozzle should extend through front opening
   - Motor should be accessible from rear
   - Volute should sit flush against shell interior

3. **Check clearances:**
   - Minimum 10mm clearance to shell walls (vibration isolation)
   - No interference with chassis mounting brackets
   - Intake area has clear path to top vents

4. **Mark mounting points:**
   - Use blower mounting holes as template
   - Transfer marks to shell interior
   - Double-check measurements before drilling

5. **Drill mounting holes in shell:**
   - Use 5.5mm drill bit for M5 bolts
   - Deburr all holes
   - Clean metal shavings with compressed air

6. **Remove blower from shell:**
   - Set aside for painting/finishing
   - Store in safe location (protect nozzle from damage)

> **Photo Placeholder:** Blower test-fit in shell with clearances visible

### Step 6: Paint/Finish (Optional, 1-2 hours + dry time)

If 3D printed parts are not pre-finished:

1. **Surface preparation:**
   - Sand parts with 220-grit sandpaper
   - Fill layer lines with filler primer (optional)
   - Clean with isopropyl alcohol

2. **Primer (if painting):**
   - Use plastic-safe primer
   - 2-3 light coats, 10 minutes between coats
   - Let dry 1 hour

3. **Paint:**
   - Use high-temperature paint (optional, for motor area)
   - Match Muni orange if desired
   - 2-3 coats, let dry per manufacturer instructions

4. **Clear coat (optional):**
   - UV-resistant clear coat for outdoor durability
   - 2 coats
   - Let cure 24 hours before handling

**Alternative:** Leave ASA parts unpainted (ASA is UV-resistant and durable as-is)

---

## Shell Integration (Day 2 Morning)

**Time Required:** 2-3 hours
**Goal:** Blower mechanically integrated into shell and mounted to chassis

### Step 7: Mount Blower Assembly to Shell (45 minutes)

1. **Position blower in shell:**
   - Align mounting holes
   - Ensure nozzle is centered in shell opening
   - Check that motor is accessible for wiring

2. **Install vibration dampers (recommended):**
   - Use rubber washers or grommets under bolt heads
   - Helps reduce noise and vibration transmission
   - McMaster P/N: 90295A120 (M5 size)

3. **Bolt blower to shell:**
   - Use M5×16mm screws through shell into volute mounting bosses
   - Add washers under bolt heads
   - Apply blue Loctite to threads
   - Torque to snug + 1/4 turn

4. **Verify secure mounting:**
   - Try to wiggle blower assembly (should be solid)
   - Check all screws are tight
   - No rattling or loose parts

> **Photo Placeholder:** Blower mounted inside shell

### Step 8: Secure Shell to Chassis (1 hour)

The shell mounts to the rover's 2020 aluminum extrusion chassis.

1. **Position shell on rover chassis:**
   - Align with front of rover (nozzle pointing forward)
   - Center left-to-right
   - Check ground clearance (shell should not drag)

2. **Install T-nuts in chassis extrusion:**
   - Insert T-nuts into 2020 extrusion slots
   - Loosely position at mounting points
   - Align with shell mounting holes

3. **Install mounting brackets:**
   - Use custom brackets or L-brackets
   - Attach brackets to shell with M5 screws
   - Attach brackets to chassis with M5 screws into T-nuts

4. **Tighten all mounting hardware:**
   - Chassis-to-bracket: 5 Nm torque
   - Bracket-to-shell: snug + 1/4 turn
   - Apply blue Loctite to critical fasteners

5. **Check rigidity:**
   - Push down on shell (should not flex)
   - No movement relative to chassis
   - All mounting points load-bearing

> **Photo Placeholder:** Shell mounted to chassis with visible brackets

### Step 9: Install Intake Vent Baffles (30 minutes)

Intake vents allow air to enter the blower while preventing debris from entering.

1. **Locate intake vent positions:**
   - Top rear of shell
   - Should have clear path to volute intake
   - Multiple smaller vents preferred over one large vent

2. **Install vent baffles:**
   - Baffles prevent rain from entering
   - Use louver-style or mesh-covered openings
   - Secure with M3 screws or adhesive

3. **Verify airflow path:**
   - Air should flow: vents → volute → impeller → nozzle
   - No obstructions or sharp bends
   - Use smoke pencil or tissue test to verify flow direction

> **Photo Placeholder:** Intake vents installed on shell top

### Step 10: Install Drain Grommets (15 minutes)

Drain grommets allow water to escape if rain enters the shell.

1. **Locate low points in shell:**
   - Water will pool at lowest interior points
   - Typically bottom rear corners

2. **Drill 6mm holes for grommets:**
   - Deburr holes
   - Clean metal shavings

3. **Install rubber grommets:**
   - Push into holes from interior
   - Should seat flush
   - Allows water to drain but prevents debris from entering

---

## Electrical Integration (Day 2 Afternoon)

**Time Required:** 2-3 hours
**Goal:** Blower powered and controllable via CAN bus

### Step 11: Route 48V Power from Battery (45 minutes)

**SAFETY:** Work with rover powered OFF. Verify with multimeter before touching any wires.

1. **Identify battery power tap point:**
   - Locate main 48V battery distribution point
   - Ensure fuse or circuit breaker is available
   - Check wire gauge (14 AWG minimum for 10A load)

2. **Cut and strip power wires:**
   - Cut silicone wire to length (measure carefully)
   - Strip 5mm of insulation from each end
   - Twist strands tightly

3. **Install inline fuse (recommended):**
   - Use 15A blade fuse or equivalent
   - Protects blower circuit from overcurrent
   - Mount fuse holder in accessible location

4. **Route wires to blower location:**
   - Follow existing wire harnesses
   - Avoid sharp edges (use grommets where passing through metal)
   - Leave 300mm extra length at blower end (for service)
   - Secure with zip ties every 150mm

5. **Label wires:**
   - Use heat shrink labels or tape
   - Mark: "48V BLOWER +" and "48V BLOWER -"
   - Critical for safety during service

> **Photo Placeholder:** Power wires routed along chassis

### Step 12: Connect VESC Motor Controller (1 hour)

The VESC controls blower speed via CAN commands from the rover's main computer.

1. **Mount VESC near blower:**
   - Use M3 screws to mount to chassis or shell interior
   - Ensure adequate ventilation around VESC
   - Avoid locations where water could drip on it

2. **Connect battery power to VESC:**
   - Solder XT60/XT90 connector to 48V wires
   - Connect to VESC power input
   - Observe polarity (red=+, black=-)
   - **DOUBLE CHECK POLARITY BEFORE POWERING ON**

3. **Connect VESC to blower motor:**
   - Motor has 3 phase wires (typically yellow, blue, black)
   - Phase order determines direction (doesn't matter for blower)
   - Solder motor wires to VESC motor output
   - Use 14 AWG wire or heavier
   - Heat shrink all connections

4. **Connect CAN bus:**
   - VESC has CAN-H and CAN-L terminals
   - Daisy-chain from existing VESC CAN bus
   - Use twisted pair wire (22 AWG)
   - Observe correct polarity (CAN-H to CAN-H, CAN-L to CAN-L)

5. **Configure VESC CAN address:**
   - Use VESC Tool software via USB
   - Set unique CAN ID (suggest: 10 for blower)
   - Configure motor parameters:
     - Motor type: BLDC
     - Battery voltage: 48V
     - Battery cutoff: 42V
     - Max motor current: 40A
     - Max battery current: 15A
   - Save configuration to VESC

6. **Verify VESC configuration:**
   - Check motor detection was successful
   - Test motor spins in VESC Tool (low duty cycle)
   - No error codes displayed

> **Photo Placeholder:** VESC wired to blower motor with CAN bus

### Step 13: Apply Conformal Coating (30 minutes)

Conformal coating protects electrical connections from moisture and corrosion.

**IMPORTANT:** Work in well-ventilated area. Coating is flammable and has strong fumes.

1. **Prepare surfaces:**
   - Clean all connections with isopropyl alcohol
   - Let dry completely (5 minutes)
   - Mask off areas that shouldn't be coated (connectors, vents)

2. **Apply conformal coating:**
   - Use MG Chemicals 422B or equivalent
   - Brush or spray onto:
     - Solder joints
     - Wire terminations
     - VESC PCB (avoid connectors)
   - Apply thin, even coat (2-3 coats better than one thick coat)

3. **Cure coating:**
   - Let dry per manufacturer instructions (typically 1-4 hours)
   - Full cure: 24 hours
   - Do not operate blower until coating is dry

> **Photo Placeholder:** Coated connections (before final cure)

### Step 14: Cable Management (30 minutes)

Proper cable management prevents chafing, interference, and maintenance issues.

1. **Bundle power wires:**
   - Use zip ties every 150mm along wire runs
   - Avoid over-tightening (can damage insulation)
   - Leave service loops at connections

2. **Secure CAN bus wires:**
   - Keep CAN wires away from high-current power wires (EMI)
   - Use cable lacing or spiral wrap
   - Protect from abrasion at any sharp edges

3. **Final inspection:**
   - Tug test all connections (should not pull free)
   - Check for any exposed wire
   - Verify no wires are pinched or under tension
   - Ensure all wires are secured (nothing hanging loose)

4. **Documentation:**
   - Take photos of wiring for reference
   - Note VESC CAN ID in system documentation
   - Update rover wiring diagram if applicable

> **Photo Placeholder:** Clean cable routing with labeled wires

### Step 15: Wiring Diagram

```
                                    ┌───────────────────────────────┐
                                    │  Rover Main Battery (48V)     │
                                    │  13S Li-ion, 20Ah             │
                                    └────────┬──────────────────────┘
                                             │
                                       [15A Fuse]
                                             │
                                    ┌────────┴────────┐
                                    │  14 AWG Power   │
                       Red (+48V) ──┤                 │
                       Black (GND) ─┤                 │
                                    └────────┬────────┘
                                             │
                                             │ XT60 Connector
                                             │
                        ┌────────────────────┴─────────────────────┐
                        │         VESC 75/300                      │
                        │         CAN ID: 10                       │
                        │                                          │
                        │  Power In:  +48V, GND                   │
                        │  Motor Out: Phase A, B, C (3 wires)     │
                        │  CAN Bus:   CAN-H, CAN-L (twisted pair) │
                        └───────┬────────────────┬─────────────────┘
                                │                │
                        Motor Phase Wires        │ CAN Bus (22 AWG twisted pair)
                                │                │
                                │                │ CAN-H (Yellow)
                    ┌───────────┴──────┐         │ CAN-L (Green)
                    │  90mm EDF Motor  │         │
                    │  Brushless, 48V  │         └─────> To other VESCs (daisy chain)
                    │  Max 40A         │                 Termination: 120Ω at each end
                    └──────────────────┘

Notes:
- All power connections use 14 AWG silicone wire minimum
- CAN bus uses 22 AWG twisted pair
- Inline 15A fuse protects blower circuit
- VESC CAN ID must be unique (suggest ID 10)
- Phase wire order doesn't matter (determines spin direction only)
```

---

## Bench Testing

**Time Required:** 1-2 hours
**Goal:** Verify blower operates safely at all power levels before field deployment

**SAFETY FIRST:**
- Wear safety glasses at all times
- Wear hearing protection above 50% power
- Keep hands, tools, and loose clothing away from impeller
- Secure rover to prevent movement during testing
- Have emergency stop readily accessible

### Test 1: Power-On Checklist (15 minutes)

Before first power-on, verify all critical items:

- [ ] **Electrical:**
  - [ ] Battery voltage measures 48V ± 2V
  - [ ] All polarities correct (no reversed connections)
  - [ ] No short circuits (multimeter test)
  - [ ] Fuse installed in blower circuit
  - [ ] VESC power LED illuminates when powered
  - [ ] CAN bus terminators in place (120Ω at each end)

- [ ] **Mechanical:**
  - [ ] Impeller spins freely by hand
  - [ ] No obstructions in airflow path
  - [ ] All mounting bolts tight
  - [ ] No loose wires near impeller
  - [ ] Intake vents clear

- [ ] **Software:**
  - [ ] Rover `bvrd` daemon running
  - [ ] VESC detected on CAN bus (check logs)
  - [ ] Blower control available in depot console
  - [ ] E-stop functional

### Test 2: Spin-Up Test (30 minutes)

Gradually increase blower speed while monitoring for issues.

1. **Initial power-on (0% → 10%):**
   - Set blower to 10% power via depot console
   - Impeller should start spinning smoothly
   - Listen for unusual noises (grinding, squealing, rattling)
   - Verify rotation direction (doesn't matter, but should be consistent)

2. **Low power test (10% → 30%):**
   - Increase to 30% in 5% increments
   - Hold each level for 30 seconds
   - Monitor:
     - Vibration (should be minimal)
     - Sound (should be smooth hum, no rattling)
     - Airflow (should feel at nozzle outlet)

3. **Medium power test (30% → 60%):**
   - Increase to 60% in 10% increments
   - Hold each level for 30 seconds
   - Monitor same parameters as above
   - Airflow should be strong and consistent

4. **High power test (60% → 100%):**
   - Increase to 100% in 10% increments
   - Hold at 100% for 60 seconds
   - **Expected behavior:**
     - Strong, steady airflow
     - Smooth sound (turbine-like)
     - Minimal vibration
   - **Unacceptable behavior (STOP IMMEDIATELY):**
     - Loud rattling or grinding
     - Excessive vibration
     - Burning smell
     - VESC error lights

5. **Shutdown test:**
   - Reduce power to 0%
   - Impeller should coast down smoothly (15-30 seconds)
   - No sudden stops or grinding

> **Photo Placeholder:** Blower running during bench test

### Test 3: Current Draw Measurement (15 minutes)

Measure electrical current to verify system is within specifications.

1. **Setup clamp meter:**
   - Clamp around positive power wire to VESC
   - Set meter to DC current mode
   - Zero meter if applicable

2. **Measure current at various power levels:**

   | Power Level | Expected Current | Actual Current | Notes |
   |-------------|------------------|----------------|-------|
   | 10%         | ~1-2A           |                |       |
   | 30%         | ~3-5A           |                |       |
   | 50%         | ~6-10A          |                |       |
   | 80%         | ~12-18A         |                |       |
   | 100%        | ~15-25A         |                |       |

3. **Verify current is within limits:**
   - Should not exceed VESC battery current limit (15A typical)
   - Should not trip inline fuse (15A)
   - If current is too high, reduce max power in VESC settings

4. **Calculate power consumption:**
   - Power (W) = Voltage (V) × Current (A)
   - At 100%: ~48V × 20A = ~960W maximum
   - Battery runtime: 20Ah ÷ 20A = ~1 hour at 100% (theoretical)

### Test 4: Vibration Check (15 minutes)

Excessive vibration can indicate imbalance, misalignment, or mounting issues.

1. **Visual inspection at operating speed:**
   - Run blower at 50% power
   - Observe impeller through intake (if visible)
   - Should spin true with no wobble

2. **Hand vibration test:**
   - Lightly touch shell exterior near blower
   - Should feel smooth vibration, no harsh buzzing
   - Compare to motor VESCs (blower should be similar or less)

3. **Listening test:**
   - Stand 1m from blower
   - Listen for:
     - Smooth turbine sound: GOOD
     - Rhythmic thumping: BAD (unbalanced impeller)
     - High-pitched squeal: BAD (bearing issue)
     - Rattling: BAD (loose parts)

4. **If excessive vibration detected:**
   - Power down immediately
   - Check impeller set screw tightness
   - Verify impeller is not damaged
   - Check motor mounting bolts
   - Re-test after corrections

### Test 5: Thermal Test (30 minutes)

Verify system does not overheat during extended operation.

1. **Baseline temperature measurement:**
   - Measure ambient air temperature
   - Measure VESC heatsink temperature (should be ~ambient)
   - Measure motor housing temperature (should be ~ambient)

2. **Run at 80% power for 15 minutes:**
   - Simulates sustained demo operation
   - Monitor temperatures every 5 minutes:

   | Time | VESC Temp | Motor Temp | Notes |
   |------|-----------|------------|-------|
   | 0min | ___°C     | ___°C      |       |
   | 5min | ___°C     | ___°C      |       |
   | 10min| ___°C     | ___°C      |       |
   | 15min| ___°C     | ___°C      |       |

3. **Acceptable temperature limits:**
   - VESC heatsink: <70°C (140°F)
   - Motor housing: <80°C (176°F)
   - If temps exceed limits, increase cooling or reduce max power

4. **Cool-down test:**
   - Reduce to 0% power
   - Monitor temperature decrease
   - Should return to near-ambient within 10 minutes

5. **Long-term thermal considerations:**
   - If running >30 min continuously, consider adding cooling fan
   - Ensure intake vents are not blocked during operation
   - Monitor temps during debris testing (additional load)

---

## Debris Testing

**Time Required:** 1-2 hours
**Goal:** Determine optimal power settings and effective range for debris clearing

**Test Objects:**
- [ ] Paper (single sheet, 8.5×11")
- [ ] Paper cup (empty, 16oz)
- [ ] Plastic bottle (empty, 500ml)
- [ ] Leaves (if available)
- [ ] Tennis ball (worst-case heavy object)

### Test 6: Effective Range at Various Power Levels (45 minutes)

Determine at what distance the blower can move various objects.

**Setup:**
1. Mark distances on floor: 2ft, 5ft, 8ft, 10ft, 15ft
2. Place test object at each distance
3. Run blower at various power levels
4. Record if object moves

**Test Matrix:**

| Object | Power Level | 2ft | 5ft | 8ft | 10ft | 15ft | Notes |
|---|---|-----|-----|-----|---|---|---|
| Paper  | 30% | | | | | | |
| Paper  | 50% | | | | | | |
| Paper  | 80% | | | | | | |
| Cup | 30% | | | | | | |
| Cup | 50% | | | | | | |
| Cup | 80% | | | | | | |
| Bottle | 50% | | | | | | |
| Bottle | 80% | | | | | | |
| Bottle | 100% | | | | | | |

**Expected Results:**
- Paper should move at 8-10ft with 50% power
- Cup should move at 5-8ft with 50% power
- Bottle should move at 3-5ft with 80% power

### Test 7: Demo Power Level Optimization (30 minutes)

Find the "sweet spot" for live demonstrations.

**Goals:**
- Impressive but not dangerous
- Reliable object movement
- Reasonable battery consumption
- Not excessively loud

**Recommended Settings:**
- **Cruise power:** 40-50% (background operation during patrol)
- **Demo power:** 80-90% (when approaching object)
- **Max power:** 100% (reserved for heavy objects or wow factor)

**Demo Choreography Practice:**
1. Rover approaches object at 3 mph, blower at 50%
2. At 8 feet: Operator sees object, maintains 50%
3. At 5 feet: Object starts to move from airflow
4. At 3 feet: Operator boosts to 80% via console
5. Object tumbles aside dramatically
6. Rover passes, operator returns to 50%

**Practice this sequence 10 times with various objects to build operator confidence.**

### Test 8: Safety Checks (15 minutes)

Verify blower does not pose safety risks during demo.

1. **Max airflow test:**
   - Person stands in front of blower at 5ft
   - Run blower at 100%
   - Airflow should be strong but not painful
   - No flying debris created

2. **Noise level test:**
   - Measure sound level at 3ft with smartphone app
   - Target: <85 dB at 80% power (safe for 8hr exposure)
   - If too loud, add sound dampening or reduce max power

3. **Emergency stop test:**
   - Run blower at 100%
   - Trigger emergency stop
   - Blower should shut down within 1 second
   - Verify impeller coasts safely (no sudden stop)

4. **Fail-safe test:**
   - Disconnect CAN bus while blower running
   - Blower should shut down or go to safe state
   - Verify behavior matches firmware expectations

---

## Troubleshooting

### Common Issues and Fixes

#### Issue: Blower won't start / no response to commands

**Symptoms:**
- VESC powered on (LED lit) but motor doesn't spin
- No response when changing power level in console

**Diagnosis:**
1. Check VESC CAN ID matches firmware expectations
   - Use VESC Tool to verify CAN ID (should be 10)
   - Check `bvrd` logs for CAN communication errors
2. Verify CAN bus wiring polarity
   - CAN-H to CAN-H, CAN-L to CAN-L
   - Swap wires if necessary and re-test
3. Check VESC motor detection
   - Re-run motor detection in VESC Tool
   - Verify motor parameters are saved

**Fix:**
- Correct CAN ID in VESC Tool, save configuration
- Fix CAN bus wiring if reversed
- Re-run motor detection and save parameters

---

#### Issue: Excessive vibration or noise

**Symptoms:**
- Blower rattles or vibrates harshly
- Rhythmic thumping sound
- Vibration felt throughout rover chassis

**Diagnosis:**
1. Check impeller set screw
   - Remove volute cover if needed
   - Verify set screw is tight
   - Check for shaft flat engagement
2. Inspect impeller for damage
   - Look for broken blades
   - Check for cracks or deformation
3. Check motor mounting bolts
   - Verify all bolts are tight
   - Check for cracks in volute housing

**Fix:**
- Tighten impeller set screw with Loctite
- Replace impeller if damaged (use spare)
- Tighten motor mounting bolts
- If vibration persists, motor may be damaged (replace)

---

#### Issue: Low airflow / weak performance

**Symptoms:**
- Blower runs but airflow is weak
- Cannot move objects that should be within range
- Motor spins but little air output

**Diagnosis:**
1. Check for obstructions
   - Inspect intake vents (blocked?)
   - Check volute interior (debris?)
   - Verify nozzle is clear
2. Check impeller direction
   - Should blow OUT of nozzle, not suck IN
   - If reversed, swap any two motor phase wires
3. Check for air leaks
   - Inspect volute-to-nozzle seal
   - Check for cracks in housing

**Fix:**
- Clear any obstructions
- Reverse motor direction if needed (swap two phase wires)
- Re-seal volute-to-nozzle junction with RTV sealant
- Replace housing if cracked

---

#### Issue: VESC overheating

**Symptoms:**
- VESC very hot to touch (>70°C)
- VESC thermal protection shuts down motor
- VESC error LED flashing

**Diagnosis:**
1. Check current draw
   - Measure with clamp meter
   - Should be <15A at 100% power
2. Check VESC mounting
   - Should have thermal contact to metal heatsink
   - Ensure adequate airflow around VESC
3. Check motor parameters
   - Max current settings may be too high

**Fix:**
- Reduce max battery current in VESC settings (try 12A)
- Add heatsink or cooling fan to VESC
- Improve airflow around VESC mounting location
- Limit max power to 80% if problem persists

---

#### Issue: Blower works intermittently

**Symptoms:**
- Blower starts and stops randomly
- Works sometimes, fails other times
- CAN communication errors in logs

**Diagnosis:**
1. Check power connections
   - Verify XT60 connector is fully seated
   - Check for loose solder joints
   - Measure voltage at VESC (should be 48V ± 2V)
2. Check CAN bus connections
   - Verify twisted pair is intact
   - Check for damaged wire insulation
   - Ensure termination resistors in place
3. Check for shorts or ground loops
   - Use multimeter to check resistance to ground

**Fix:**
- Re-solder any cold joints
- Replace damaged CAN bus wires
- Ensure proper termination (120Ω at each end of bus)
- Add ferrite beads to CAN wires if EMI suspected

---

#### Issue: Current draw too high / fuse blows

**Symptoms:**
- Inline fuse blows when blower at high power
- Current exceeds 15A (typical limit)
- Battery protection trips

**Diagnosis:**
1. Check motor resistance
   - Measure phase-to-phase resistance (should be ~0.1-0.5Ω)
   - Low resistance = high current
2. Check for mechanical binding
   - Spin impeller by hand (should be smooth)
   - Check for rubbing against volute
3. Check VESC current limits
   - Verify battery current limit is set correctly

**Fix:**
- Reduce max duty cycle in VESC settings
- Check for mechanical issues (binding, rubbing)
- Use higher-current fuse (20A) if motor and wiring can handle it
- Limit max power to 80% in firmware

---

### Spare Parts to Have On Hand

Keep these spares available during demo days:

**Critical (have at demo):**
- [ ] Spare impeller (pre-balanced)
- [ ] Spare VESC (pre-configured with correct CAN ID)
- [ ] Inline fuse (15A, same type as installed)
- [ ] XT60/XT90 connectors (2x pairs)
- [ ] Assorted M5 and M4 bolts
- [ ] Blue Loctite
- [ ] Zip ties (assorted sizes)
- [ ] Electrical tape
- [ ] Multimeter

**Nice to Have (keep in shop):**
- [ ] Complete 3D printed volute housing
- [ ] Complete 3D printed nozzle
- [ ] 90mm EDF motor (complete unit)
- [ ] 1m each 14 AWG red/black wire
- [ ] Heat shrink tubing
- [ ] Conformal coating (small bottle)
- [ ] Rubber vibration dampers

---

## Final Checklist

Before declaring blower integration complete:

**Mechanical:**
- [ ] All bolts torqued and Loctite applied
- [ ] No rattles or vibrations at any power level
- [ ] Impeller spins freely, no rubbing
- [ ] Shell securely mounted to chassis
- [ ] Intake vents clear and baffled
- [ ] Drain grommets installed

**Electrical:**
- [ ] All connections soldered and heat-shrunk
- [ ] Conformal coating applied and cured
- [ ] VESC configured with correct CAN ID
- [ ] Inline fuse installed
- [ ] Wires secured and labeled
- [ ] No exposed wire or short circuits

**Testing:**
- [ ] Spin-up test passed (0-100% smooth)
- [ ] Current draw within limits (<15A at 100%)
- [ ] Vibration check passed
- [ ] Thermal test passed (15min at 80%, <70°C)
- [ ] Debris test completed, optimal power determined
- [ ] Emergency stop functional
- [ ] Demo choreography practiced 10+ times

**Documentation:**
- [ ] Photos taken of wiring and assembly
- [ ] VESC CAN ID recorded in system docs
- [ ] Test results logged
- [ ] Known issues documented
- [ ] Spare parts inventory confirmed

**Demo Readiness:**
- [ ] Operator trained on blower control
- [ ] Backup battery charged
- [ ] Spare impeller on-site
- [ ] Tools for quick fixes available
- [ ] Failure mode responses practiced

---

## Notes

**Revision History:**
- v1.0 (2026-01-14): Initial guide created for F.Inc Artifact Week 4

**Contributors:**
- Assembly guide authored for Muni BVR blower integration

**Feedback:**
If you encounter issues not covered in this guide, or have suggestions for improvement, document them for future revisions.

---

**Good luck with your assembly. Take your time, double-check everything, and don't skip the testing steps. A well-built blower system will make for an impressive demo.**

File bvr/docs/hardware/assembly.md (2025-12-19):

# Assembly Guide

## Bill of Materials

### Chassis

| Part | Qty | Source |
| --- | --- | --- |
| 2020 extrusion 600mm | 8 | 80/20, Misumi |
| 2020 corner bracket  | 16  | Amazon |
| M5×10 button head | 64  | McMaster |
| M5 T-nut | 64  | Amazon |

### Drivetrain

| Part | Qty | Source |
| --- | --- | --- |
| Hoverboard hub motor | 4 | eBay, AliExpress |
| VESC 6 | 4 | Trampa, Flipsky  |
| Motor mount bracket  | 4 | Custom (CAD) |
| Wheel adapter | 4 | Custom (CAD) |

### Electronics

| Part | Qty | Source |
| --- | --- | --- |
| Jetson Orin NX | 1 | NVIDIA |
| 13S 20Ah battery  | 1 | Custom or supplier |
| 48V→12V DCDC 20A  | 1 | Amazon |
| CAN transceiver | 1 | Amazon (MCP2551) |
| E-Stop relay 100A | 1 | Amazon |
| E-Stop button | 1 | Amazon |
| LTE modem | 1 | Sierra Wireless |

### Wiring

| Part | Qty | Source |
| --- | --- | --- |
| 8 AWG silicone wire | 3m  | Amazon |
| 14 AWG silicone wire | 5m  | Amazon |
| 22 AWG twisted pair | 3m  | Amazon |
| XT90 connectors | 4 | Amazon |
| XT30 connectors | 10  | Amazon |
| Heat shrink assortment | 1 | Amazon |

## Assembly Steps

### 1. Chassis Frame

1. Cut extrusions to length (if not pre-cut)
2. Deburr all cuts
3. Assemble base rectangle (600×600mm)
4. Add corner gussets for rigidity
5. Mount vertical supports for electronics

### 2. Motor Mounting

1. Attach motor mount brackets to extrusion
2. Install hub motors into brackets
3. Route phase wires to VESC locations
4. Ensure wheels spin freely

### 3. Electronics Mounting

1. Mount electronics plate to chassis
2. Install Jetson with standoffs
3. Mount VESCs with thermal pad to plate
4. Install DCDC converter
5. Route all power wiring

### 4. Wiring

**Power:**

1. Connect battery to main fuse
2. Wire fuse → E-Stop relay → VESCs
3. Wire battery → DCDC → Jetson/accessories
4. Install XT90 for battery disconnect

**Signal:**

1. Connect CAN bus daisy chain
2. Add 120Ω termination resistors
3. Wire E-Stop button to relay
4. Connect LTE modem to Jetson USB

### 5. Testing

1. Check all connections with multimeter
2. Power on with battery (no motors first)
3. Verify Jetson boots
4. Verify VESCs initialize
5. Test E-Stop cuts power
6. Run motor spin test (wheels off ground)

## Tool Mounting

Tools attach via:

- Quick-release mechanical mount (front)
- Deutsch DT connector (power + CAN)

See individual tool assembly guides in respective repos.

## Quality Checklist

- [ ] All bolts torqued
- [ ] No exposed wiring
- [ ] CAN termination verified
- [ ] E-Stop tested
- [ ] No rubbing/interference when wheels spin
- [ ] Battery secure and protected
- [ ] All connectors fully seated
- [ ] Thermal management adequate

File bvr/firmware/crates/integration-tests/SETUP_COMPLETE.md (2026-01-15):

# Test Infrastructure Setup Complete! ✅

## What We Built

### 1. SLAM & Localization Review Skill
**Location:** `.claude/skills/slam-localization-review/SKILL.md`

A comprehensive code review skill for Week 2 of your Artifact program covering:
- Coordinate frame management (world/odom/base/lidar)
- Differential drive odometry with covariance propagation
- Extended Kalman Filter for sensor fusion
- Correlative scan matching (more robust than ICP)
- Pose graph SLAM with loop closure detection
- Occupancy grid mapping with log-odds
- Performance & real-time constraints (100Hz target)
- Numerical stability & error handling
- Testing strategies

**How to use:**
```bash
# During code review
/slam-localization-review

# Or just reference it in questions
"Review my scan matching implementation using the SLAM skill"
```

### 2. Integration Test Suite
**Location:** `bvr/firmware/crates/integration-tests/`

A complete testing infrastructure with:
- **7 integration tests** (5 passing, 2 need math tuning, 3 TODO for Week 2-4)
- **Test utilities** in `common/` module (synthetic scans, differential drive simulation)
- **Comprehensive README** with testing strategies and examples

**Current Test Results:**
```
✅ test_odometry_straight_line
✅ test_angle_normalization
✅ test_covariance_stays_positive_definite
✅ test utilities (box room scan, differential drive sim)
⚠️  test_odometry_arc_motion (math needs tuning)
⚠️  test_coordinate_frame_chain (floating point precision)
🔜 test_slam_square_loop (#[ignore] - implement in Week 2)
🔜 test_path_planning_around_obstacle (#[ignore] - implement in Week 3)
🔜 test_full_autonomy_pipeline (#[ignore] - implement in Week 4)
```

**How to use:**
```bash
# Run all integration tests
cargo test -p integration-tests

# Run specific test
cargo test -p integration-tests test_odometry_straight_line

# Run with logging
RUST_LOG=debug cargo test -p integration-tests -- --nocapture

# Include ignored tests (when implementing SLAM/planning)
cargo test -p integration-tests -- --ignored
```

## What This Enables

### For Week 1 (Transit + Foundation)
- ✅ Test odometry integration as you implement the `odometry` crate
- ✅ Validate coordinate frame transforms in the `transforms` crate
- ✅ Verify covariance propagation stays numerically stable

### For Week 2 (SLAM + Localization)
- Use `/slam-localization-review` to review scan matching code
- Uncomment the `test_slam_square_loop` test and implement it
- Generate Rerun recordings for visual debugging

### For Week 3 (Navigation + Obstacles)
- Implement `test_path_planning_around_obstacle`
- Add tests for costmap layering and inflation
- Test DWA local planner trajectory generation

### For Week 4 (Integration + Polish)
- Implement `test_full_autonomy_pipeline`
- Run 10+ consecutive tests without failures (demo requirement!)
- Add performance benchmarks (100Hz state estimation)

## Quick Start

1. **Write some odometry code** in a new `bvr/firmware/crates/odometry/` crate

2. **Test it immediately:**
   ```bash
   cargo test -p integration-tests test_odometry_straight_line
   ```

3. **Review it with Claude:**
   ```bash
   # In Claude Code
   "Review my odometry implementation using /slam-localization-review"
   ```

4. **Iterate fast** - tests catch bugs before they become demo failures!

## Next Steps

1. **Week 1 Tasks:**
   - Implement `lidar` crate (RPLidar driver)
   - Implement `transforms` crate (coordinate frames)
   - Implement `odometry` crate (differential drive)
   - Add tests for each crate to `integration-tests/`

2. **Create More Skills:**
   When you start Week 3 path planning, create:
   ```bash
   /skill-architect analyze path planning from artifact-plan.md
   ```

3. **Expand Test Coverage:**
   As you implement each autonomy module, add tests:
   - `test_scan_matching_robustness.rs`
   - `test_ekf_sensor_fusion.rs`
   - `test_hybrid_astar_planner.rs`
   - `test_dwa_obstacle_avoidance.rs`

## Test-Driven Development Workflow

```bash
# 1. Write a failing test
cargo test -p integration-tests test_new_feature
# FAILS ❌

# 2. Implement the feature
# Edit bvr/firmware/crates/slam/src/scan_matcher.rs

# 3. Run test again
cargo test -p integration-tests test_new_feature
# PASSES ✅

# 4. Review with Claude
"Review my scan matching implementation"

# 5. Commit
git add -A
git commit -m "feat(slam): implement correlative scan matcher

- Add coarse + fine search
- Estimate covariance from score surface
- Tests pass with <5cm accuracy

Co-Authored-By: Claude Sonnet 4.5 <noreply@anthropic.com>"
```

## Files Created

```
.claude/skills/slam-localization-review/
└── SKILL.md                                    # 600+ line review skill

bvr/firmware/crates/integration-tests/
├── Cargo.toml                                  # Test package config
├── README.md                                   # Testing guide (6.9KB)
├── SETUP_COMPLETE.md                           # This file
├── src/lib.rs                                  # Empty (tests-only crate)
└── tests/
    ├── autonomy_integration.rs                 # 7 integration tests
    └── common/
        └── mod.rs                              # Test utilities
```

## Metrics to Track

As you implement the autonomy stack, track these in your tests:

- **Correctness:** Position error < 10cm after 10m traveled
- **Stability:** Covariance eigenvalues stay in [1e-6, 1e6]
- **Performance:** State estimation at 100Hz (10ms per loop)
- **Reliability:** 10+ consecutive runs without crashes

**Demo Day Goal:** All tests pass, 100% of the time. 🎯

---

**Ready to start Week 1!** 🚀

Use the test infrastructure and SLAM skill to build with confidence. Every commit should include tests and pass existing tests. By Week 4, you'll have a bullet-proof autonomy stack ready for demo day.

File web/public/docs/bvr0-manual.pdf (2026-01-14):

TECHNICAL MANUAL

# BVR0

Base Vectoring Rover

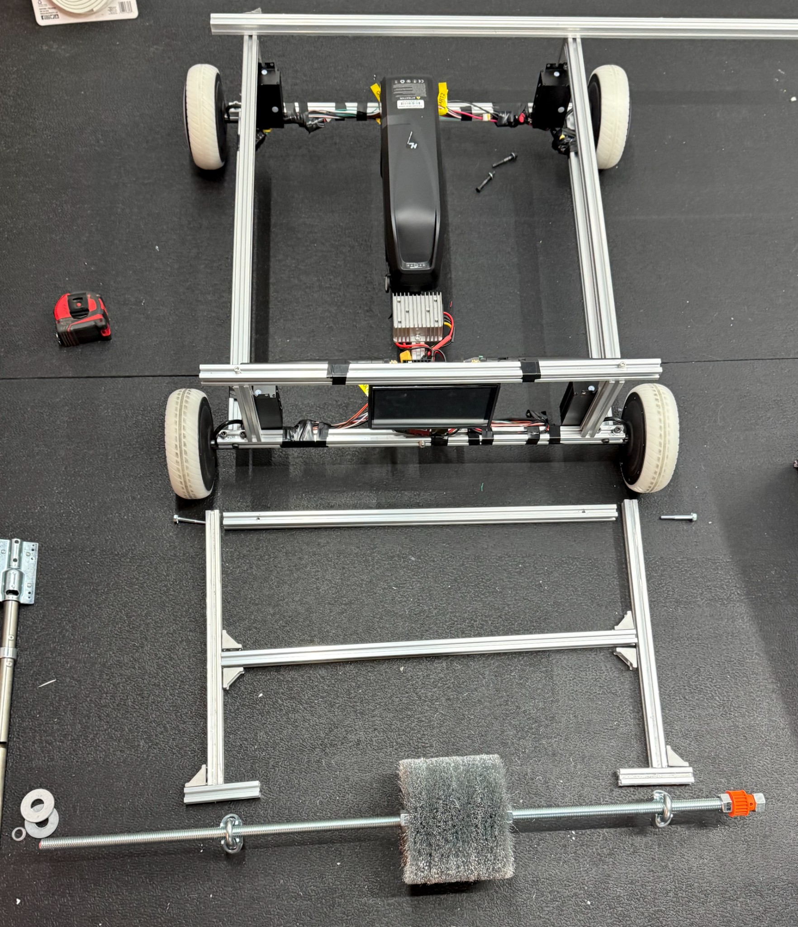
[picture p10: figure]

Revision 0.2 January 2026

Municipal Robotics
Cleveland, Ohio
muni.works

## Contents

BVR0 | Rev 0.2

## About This Manual

This manual is written by the people who built and operate BVR rovers. It’s not a marketing document or a wish list: it’s the real procedures we use, with the mistakes we’ve made and the lessons we’ve learned.

If something is unclear, wrong, or missing, let us know. This is a living document that improves with every build.

Revision History

Rev | Date | Changes
0.1 | December 2025 | Initial release
0.2 | January 2026 | Added time estimates, lessons learned, BOM, glossary

Document Conventions

Throughout this manual you’ll see:

“We learned…” | Lessons from real build experience
⚡ COMMON MISTAKE | Errors we’ve seen (and made)
| Difficulty rating (1-3)
15 min | Estimated time for procedure

ℹ NOTE This is a living document. Report errors or suggestions at github.com/muni-works/muni.

Municipal Robotics | 4

# BVR0 Cheat Sheet

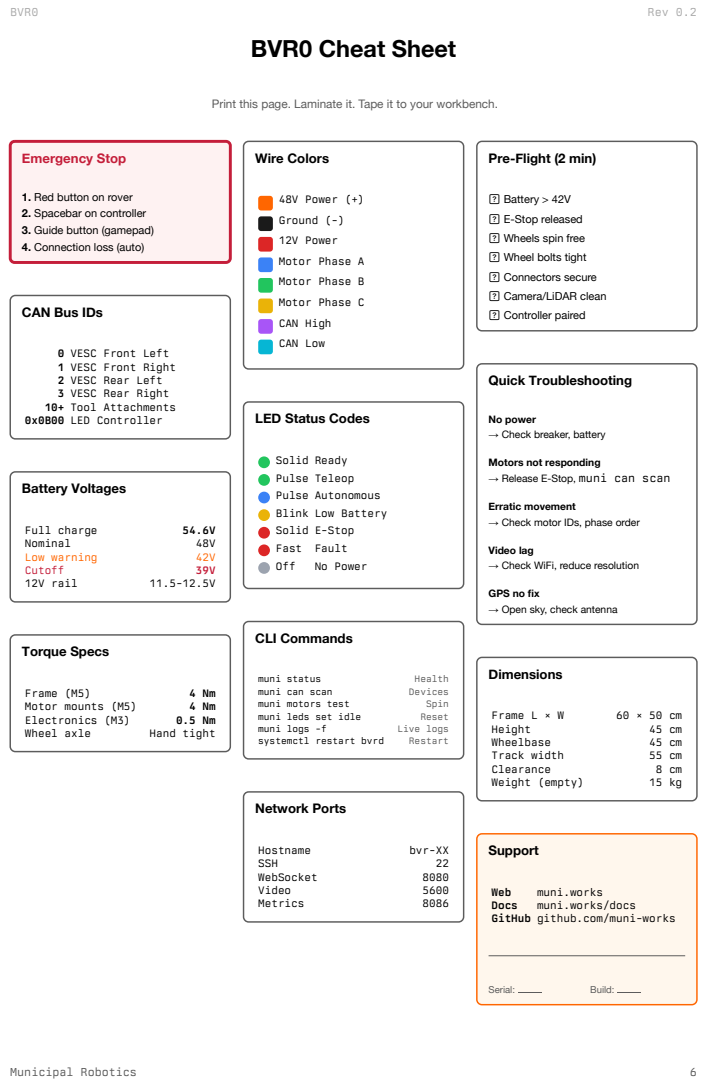
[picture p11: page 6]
Emergency Stop; Battery Voltages; Full charge; Nominal; Low warning; Cutoff; 12V rail; Torque Specs; Frame (M5); Motor mounts (M5); Electronics (M3); Wheel axle; Hand tight; Wire Colors; 48V Power (+); Ground (-); 12V Power; Motor Phase A; Motor Phase B; Motor Phase C; CAN High; CAN Low; Off; No Power; CLI Commands; muni status; Health; muni can scan; Devices; muni motors test; Spin; muni leds set idle; Reset; muni logs -f; Live logs; systemctl restart bvrd; Restart; Network Ports; Hostname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

Print this page. Laminate it. Tape it to your workbench.

Pre-Flight (2 min)

1. Red button on rover
2. Spacebar on controller
3. Guide button (gamepad)
4. Connection loss (auto)

☐ Battery > 42V
☐ E-Stop released
☐ Wheels spin free
☐ Wheel bolts tight
☐ Connectors secure
☐ Camera/LiDAR clean
☐ Controller paired

CAN Bus IDs

0 VESC Front Left
1 VESC Front Right
2 VESC Rear Left
3 VESC Rear Right
10+ Tool Attachments
0x0B00 LED Controller

LED Status Codes

No power
→ Check breaker, battery

Solid Ready
Pulse Teleop
Pulse Autonomous
Blink Low Battery
Solid E-Stop
Fast Fault

Motors not responding
→ Release E-Stop, muni can scan

Erratic movement
→ Check motor IDs, phase order

Video lag
→ Check WiFi, reduce resolution

GPS no fix
→ Open sky, check antenna

GitHub github.com/muni-works

## Quick Reference

These three pages are the ones you’ll use daily. Memorize the e-stop methods. Run the pre-flight checklist every time. Keep the controls layout in your head. Everything else in this manual is for building and fixing. This section is for operating.

## Emergency Stop

⚠ DANGER Know this page. If anything goes wrong, use one of these three methods immediately.

PHYSICAL
BUTTON

Red mushroom
button on rover

1

SPACEBAR

Press spacebar
on controller

2

DISCONNECT

Connection loss
auto-triggers

3

## ALL MOTORS STOP

When to E-Stop:
- Person in path of rover
- Unexpected movement
- Smoke, sparks, or fire
- Loss of control
- Any doubt about safety

To resume after E-Stop:
1. Resolve the cause
2. Release physical button (if used)
3. Reconnect controller
4. Verify telemetry on dashboard
5. Resume operation

## Pre-Flight Checklist

Daily inspection before operation | 2 min

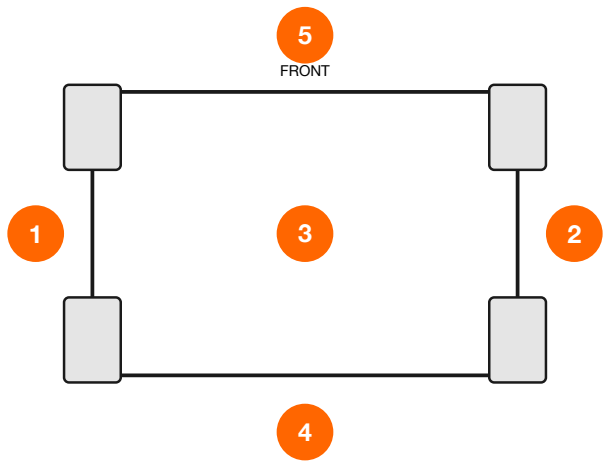
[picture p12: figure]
FRONT

ℹ NOTE If any check fails, do not operate. Resolve the issue first.

“We learned this the hard way:” We once operated with a loose wheel bolt. 10 minutes in, the wheel nearly came off mid-turn. The 2-minute checklist beats a 2-hour field repair.

## Controls

Controller mapping reference | 1 min read

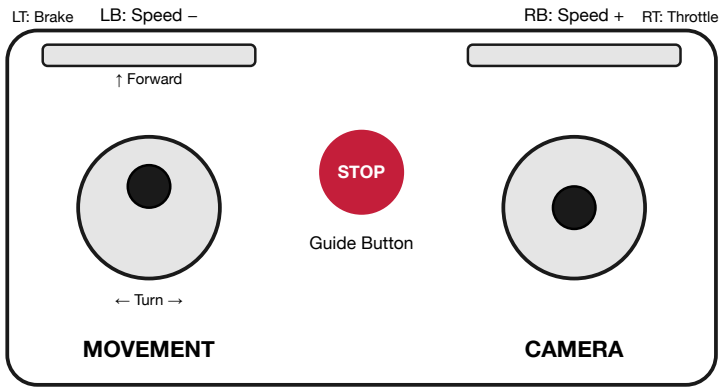
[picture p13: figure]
MOVEMENT; CAMERA; ↑ Forward; ← Turn →; LB: Speed −; RB: Speed +; STOP; Guide Button; LT: Brake; RT: Throttle

Input | Action
Left Stick Up/Down | Forward / Reverse
Left Stick Left/Right | Turn left / right
Right Stick | Pan camera view
Left Bumper (LB) | Decrease max speed
Right Bumper (RB) | Increase max speed
Left Trigger (LT) | Brake / slow down
Right Trigger (RT) | Throttle (overrides stick)
Guide Button (center) | Emergency Stop
Spacebar (keyboard) | Emergency Stop

## Before You Begin

This section explains what you’re building, what you’ll need, and how long it takes.

What You’re Building

The BVR0 is a four-wheeled skid-steer rover with hub motors, a 48V power system, and onboard compute. It’s designed for outdoor municipal work (snow clearing, mapping, patrol) but the base platform is general-purpose.

Figure 4: Four subsystems: mechanical frame, power distribution, drivetrain, and compute/sensors.

Prerequisites

Skills needed:
- Basic hand tools (hex keys, screwdrivers, wrenches)
- Wire stripping and crimping
- Soldering (through-hole level)
- Comfort with Linux command line
- Ability to read wiring diagrams

You do NOT need:
- CNC or machining (parts are outsourced or hand-cut)
- PCB design (all boards are off-the-shelf)
- Deep embedded programming (firmware is pre-built)

Build Phases

The build has four phases. Complete each before starting the next.

Total: 12-16 hours (split across 2-3 days recommended)

Recommended Order

Day | Tasks | Time
1 | Cut extrusions, assemble frame, mount motor brackets | 4-5 hr
2 | Install motors, wire power system, mount electronics plate | 4-5 hr
3 | Wire VESCs and CAN bus, flash Jetson, configure and test | 4-5 hr

✓ TIP Don’t rush. A clean build with good cable management saves hours of debugging later.

Tools Required

Essential:
- Hex key set (2, 2.5, 3, 4, 5 mm)
- Phillips screwdriver
- Wire strippers (10-22 AWG)
- Crimping tool (for ferrules)
- Soldering iron + solder
- Multimeter
- Heat gun or lighter (heat shrink)

Helpful:
- Torque wrench (4 Nm range)
- Miter saw or hacksaw (for extrusions)
- Deburring tool
- Cable tie gun
- Label maker
- Helping hands (for soldering)

Materials Checklist

Before starting, verify you have:

All BOM items received and inspected

Extrusions cut to length (or stock to cut)

Motor brackets fabricated (or ordered)

Electronics plate fabricated (or ordered)

Battery charged to 50%

Jetson flashed with JetPack

See Appendix A: Bill of Materials for the complete parts list with vendors.

## Overview

The BVR0 is the first rover in the Muni fleet. It’s intentionally simple: a rigid aluminum frame, four hub motors, and enough compute to handle autonomy. No suspension, no steering linkages, no complex mechanisms. Everything that can break has been removed.

The design philosophy is “municipal-grade”: it needs to survive Cleveland winters, sidewalk salt, and the occasional collision with a park bench. The 2020 aluminum extrusion frame can be rebuilt with hardware store parts. The hub motors are the same units used in hoverboards and e-scooters (proven, cheap, replaceable). The electronics are mounted on a single plate that slides out for service.

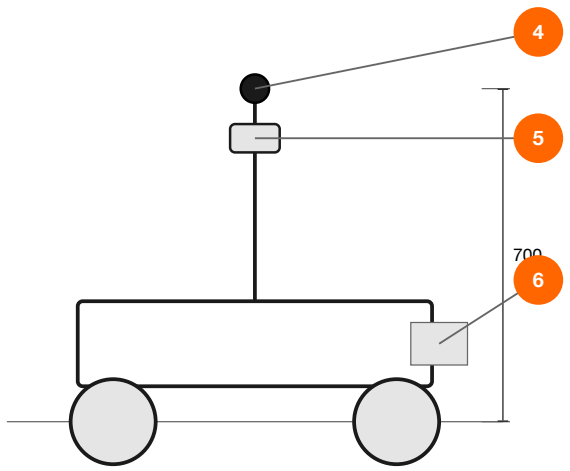
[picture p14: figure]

SIDE VIEW

### 1 Hub motor wheels (×4)

### 2 Electronics bay

### 3 Tool mount

4 360° camera

### 5 LiDAR sensor

### 6 Tool attachment

Dimensions | 600 × 600 × 700 mm
Weight | 30 kg with battery
Speed | 1.0–2.5 m/s
Runtime | 4 hours
Temp range | −20°C to +40°C

## Specifications

These are the target specifications for a standard BVR0 build. Your rover may vary slightly depending on component sourcing and local modifications.

Mechanical

Footprint | 600 × 600 mm
Height | 700 mm (with mast)
Weight | 30 kg
Ground clearance | 50 mm
Wheel diameter | 160 mm
Frame | 2020 aluminum extrusion

Electrical

Main battery | 48V 20Ah (960 Wh)
Chemistry | 13S LiPo
Voltage range | 39–54.6V
Accessory rail | 12V 10A
Main fuse | 100A

Drivetrain

Motors | 4× 350W hub motors
Controllers | 4× VESC 6.7
Drive type | Skid-steer
Max speed | 2.5 m/s
Cruise speed | 1.0 m/s

Perception

LiDAR | Livox Mid-360
Camera | Insta360 X4 (360°)
GPS | RTK-capable (optional)

Compute

Main computer | Jetson Orin NX 16GB
Connectivity | LTE + WiFi
CAN bus | 500K baud

## Required Tools

Hex Keys

2.5, 3, 4, 5 mm

Screwdriver

Phillips 2

Wrenches

8, 10, 13 mm

Multimeter

V / Ω / Continuity

Required
- Hex key set (metric: 2.5, 3, 4, 5 mm)
- Phillips screwdriver (2)
- Adjustable wrench or socket set (8, 10, 13 mm)
- Multimeter (voltage, resistance, continuity)
- Wire strippers (20-12 AWG)
- Soldering iron (40W+) and solder
- Heat shrink assortment
- Miter saw or hacksaw (for extrusions)

Recommended
- Torque wrench (4 Nm for M5)
- Drill and drill bits (3.2, 4.2, 5 mm)
- Tap set (M4×0.7, M5×0.8)
- Deburring tool
- Cable ties (assorted sizes)
- Label maker
- Work mat
- Helping hands / PCB holder

ℹ NOTE All M5 bolts should be torqued to 4 Nm. Over-tightening can strip aluminum threads.

## Parts List

A B

Jetson

C

D

48V 20Ah

E

M5 × 8

F

Parts

A Chassis: extrusions, brackets, plate | $150
B Drivetrain: motors, VESCs | $830
C Electronics: Jetson, CAN, LTE | $900
D Perception: LiDAR, camera, pole | $1,800
E Power: battery, DC-DC, E-stop | $400
F Hardware: bolts, T-nuts, wire | $100

Cost Summary

Chassis | $150
Drivetrain | $830
Electronics | $900
Perception | $1,800
Power | $400
Hardware | $100
Total | $4,180

All parts commercially available.

Full BOM with links:
docs/hardware/bom.md

Where to Buy:

Category | Primary Source
Notes | Extrusions
Amazon, Misumi | 2020 V-slot or T-slot
Motors | AliExpress
Search “hoverboard hub motor 350W” | VESCs
Flipsky | VESC 6.6 or 6.7
Jetson | NVIDIA, Arrow, Seeed
Orin NX 16GB + carrier | LiDAR
Livox / DJI Store | Mid-360, 1 week ship
Camera | Amazon, B&H
Insta360 X4 | Custom cuts
SendCutSend | Upload DXF, 3-5 day turnaround

## Custom Fabricated Parts

BVR0 requires zero custom fabricated parts.

No custom parts needed

How BVR0 avoids custom fabrication:

Component | BVR0 Approach
Alternative (BVR1) | Motor mounting
Direct bolt to 2020 T-slot | Custom brackets
Battery | Downtube e-bike battery
Custom pack + tray | Electronics
Tape/zip-tie to chassis | Custom plate

ℹ NOTE BVR0 is intentionally scrappy. The goal is to get a working rover with parts you can order today and assemble this weekend. No waiting for laser cutting, no CAD required.

Once you’ve proven the concept, BVR1 introduces custom parts for a cleaner, more serviceable build.

## Hardware Reference

Standard fasteners and hardware used throughout the build.

Bolts

Size | Use
M3×8 | Electronics mounting
M5×8 | T-nut, light duty
M5×10 | T-nut, standard
M5×12 | Motor to frame
M5×16 | T-nut, through plate

T-Nuts

Type | Use
M5 drop-in | Post-assembly insertion
M5 slide-in | Pre-assembly (easier)
M6 drop-in | Heavy-duty mounts

Connectors

Type | Rating
Use | XT90
90A | Battery main
XT60 | 60A
Motor phase | XT30
30A | 12V power
JST-PH | 3A
CAN bus, signals | DT 4-pin
25A | Tool connector

Wire Gauge

AWG | Use
8 AWG | Battery to bus
10 AWG | Bus to VESCs
14 AWG | 12V power
22 AWG | CAN bus, signals

Common Hardware (actual size)

M5 × 8

M5×8

M5 × 10

M5×10

M5 × 16
M5×16 | M5 T-Nut | Corner

## Chassis Assembly

The chassis is the skeleton of the rover. It’s built from 2020 aluminum extrusion, the same stuff used in 3D printer frames and CNC machines. The T-slot design means you can mount anything anywhere, and if you mess up a hole, just slide the T-nut to a new position.

The frame goes together like adult LEGO. No welding, no precision machining. If you can use a saw and a hex key, you can build this chassis.

## Cutting Extrusions

Cut aluminum stock to length | 20 min

Cutting Setup

2020 Extrusion

Stop

600

Fence

Procedure:
1. Clamp stop block at 600mm from blade
2. Place extrusion against fence and stop
3. Cut slowly to prevent burrs
4. Rotate 90° and re-cut if needed for square ends
5. Deburr all cut edges with file or deburring tool

Cut List (BVR0 standard):

Qty | Length
Purpose | 4
600mm | Base frame
4 | 600mm
Top frame | 4
250mm | Vertical posts

Total: 5.8m of 2020 extrusion needed.

⚠ WARNING Aluminum chips are sharp. Wear safety glasses. Clean chips from T-slots before assembly.

⚡ COMMON MISTAKE Cutting too fast causes burrs that jam T-nuts. Slow cuts with a fine-tooth blade save deburring time.

## Base Frame Assembly

Assemble the base frame square | 15 min

Assembly Steps:

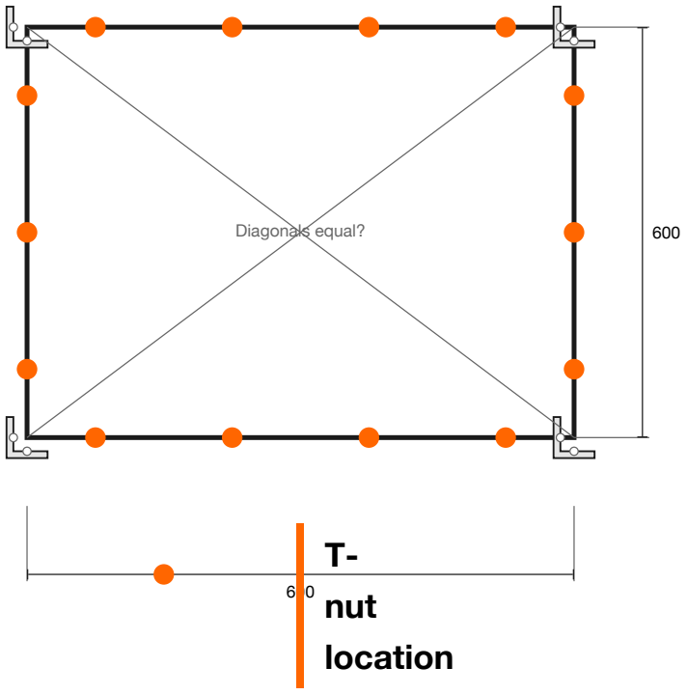
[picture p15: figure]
Diagonals equal?; nut; location

1. Pre-insert T-nuts into all extrusion channels (8 per extrusion, 32 total for base)
2. Dry-fit all four extrusions in a square, corners aligned
3. Attach corner brackets loosely (finger-tight M5×10 bolts)
4. Check squareness: measure both diagonals. They must be equal (±1mm).
5. If not square: tap the long diagonal corner with a mallet to adjust
6. Tighten all bolts to 4 Nm in a star pattern

ℹ NOTE Leave extra T-nuts in channels for later mounting. Easier now than adding drop-in nuts later.

## Vertical Posts

Install corner vertical posts | 10 min

200-400

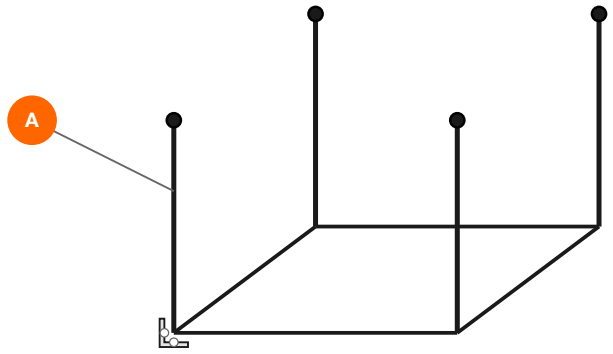
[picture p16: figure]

Mounting Method A: Corner Bracket

Use 90° corner brackets at each post base.

- 2× M5×10 bolts per bracket
- Insert T-nuts in both base and post
- Tighten to 4 Nm

Mounting Method B: Blind Joint

Use blind joint connectors for cleaner look.

- Drill 5mm access hole in base extrusion
- Thread M5×25 bolt through into post
- Hidden hardware, harder to adjust

Height Calculation:

Ground

Wheel

Clearance | 50

Base

250

350 Mast

700

Component | Height
Cumulative | Wheel radius
80mm | 80mm

Ground clearance | 50mm
– | Base to top frame
250mm posts + 40mm | 370mm
Sensor mast | 330mm

700mm

## Top Frame

Complete the box frame | 15 min

Top Frame

Assembly:

1. Attach corner brackets to top of each vertical post (loosely)
2. Place top frame extrusions onto brackets
3. Align extrusions flush with vertical posts
4. Check that top frame is level (use spirit level)
5. Tighten all connections to 4 Nm

ℹ NOTE The top frame provides mounting points for the electronics plate, sensor mast, and protective covers.

## Squareness Check

Verify frame geometry | 5 min
D2 | D1
A | B
D | C

D1 = D2 ± 1mm

Squareness Test:

1. Measure diagonal A→C (D1)
2. Measure diagonal B→D (D2)
3. Compare: D1 should equal D2 within 1mm
4. If not equal: loosen corners, tap long diagonal, retighten

Rigidity Test:

1. Grip opposite corners
2. Try to twist the frame
3. Frame should not flex or rack
4. If loose: check all bolt torque, add corner braces if needed

Final Checklist:

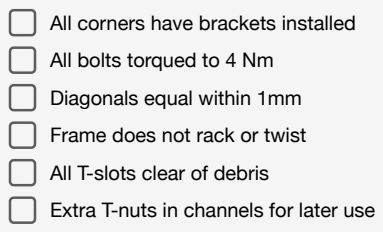
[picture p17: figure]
All corners have brackets installed; All bolts torqued to 4 Nm; Diagonals equal within 1mm; Frame does not rack or twist; All T-slots clear of debris; Extra T-nuts in channels for later use

✓ TIP Take a photo of the diagonal measurements. Useful reference if the frame gets knocked out of square later.

## Electronics Mounting

BVR0 takes the simplest possible approach: mount electronics directly to the chassis using zip ties, electrical tape, and the T-slot channels. No custom plate, no drilling, no fabrication.

This isn’t pretty, but it works. The goal of BVR0 is to get a rover running with zero custom parts. You can always upgrade to a proper electronics plate later (see BVR1 manual).

## Direct Mounting Strategy

Mount electronics to chassis | 45 min

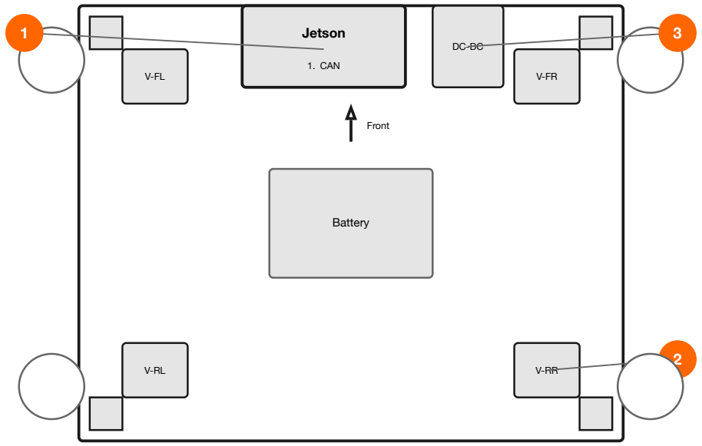
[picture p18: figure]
Jetson; 1. CAN; Battery; Front

Figure 17: VESCs at corners (on vertical posts), Jetson and DC-DC on top rail.

Components:

### 1 Jetson Orin NX + CAN board 2 VESC 6.7 ×4 (one per corner) 3 DC-DC 48V→12V

Mounting Methods:
- Electrical tape (quick, repositionable)
- Zip ties through T-slot channels
- Velcro strips (for DC-DC)
- Double-sided foam tape (vibration dampening)

## Jetson + CAN Board

Mount Jetson compute module | 15 min

The Jetson Orin NX sits on a carrier board with an integrated CAN interface. This eliminates the need for a separate USB-CAN adapter.

2020 Rail

Foam tape

Carrier board

Jetson Orin NX

CAN

Electrical tape straps

Figure 18: Jetson mounted with foam tape and electrical tape straps.

Mounting Steps:

1. Clean the extrusion surface with isopropyl alcohol
2. Apply double-sided foam tape to carrier board bottom
3. Press carrier board onto top of frame rail
4. Wrap electrical tape around rail and carrier (2-3 wraps)
5. Connect CAN board to carrier via ribbon cable or headers
6. Route power and data cables away from tape

Carrier Board with CAN:
- Waveshare or Seeed carrier with CAN
- Or: separate CAN HAT/board
- CAN-H, CAN-L, GND to VESC bus
- 120Ω termination at end of bus

Power:
- 12V from DC-DC converter
- Barrel jack or screw terminal
- 3A average, 5A peak

“We learned this the hard way:” Electrical tape sounds janky, but it’s actually great for prototyping. It’s repositionable, leaves no residue, and you can see exactly where everything is. Once the layout is proven, upgrade to proper mounts.

## VESC Mounting

Mount motor controllers | 15 min

Each VESC mounts directly to the vertical post next to its wheel. This keeps phase wires as short as possible: the motor is right there.

CORNER DETAIL

Vertical post

VESC

FL

Tape

Motor

Phase

48V

CAN

Figure 19: VESC on vertical post, directly adjacent to its motor. Minimal phase wire length.

Mounting:
- Electrical tape or Velcro to vertical post
- VESC flat against post, heatsink facing out
- Position at comfortable height for wiring
- One VESC per corner (4 total)

Wiring:
- Phase wires: direct to motor (< 15cm ideal)
- 48V power: runs from central bus to each corner
- CAN: daisy-chain around frame perimeter
- Termination: 120Ω at first and last VESC

“We learned this the hard way:” Mounting VESCs at the corners means longer power runs but shorter phase wires. Phase wires carry high-frequency switching currents: keeping them short reduces EMI and heat. The 48V DC bus doesn’t care about a few extra centimeters.

ℹ NOTE Label each VESC with its motor position (FL, FR, RL, RR). You’ll thank yourself during debugging.

## DC-DC Converter

Mount voltage regulator | 10 min

Frame rail

DC-DC

48V→12V

Velcro

48V in

12V out

Figure 20: DC-DC converter attached to frame rail with Velcro.

Mounting Tips:
- Velcro strips work well for DC-DC (easy removal)
- Route high-current wires away from signal wires
- Leave slack for service access
- Position near Jetson to minimize 12V wire runs

⚠ WARNING Don’t mount the DC-DC upside down. The heatsink needs to face up or outward for convection cooling.

ℹ NOTE BVR0 has no inline fuse. The battery’s internal BMS provides overcurrent protection. This is acceptable for a prototype but not recommended for production. BVR1 adds proper fusing.

## Wiring Overview

Route and secure cables | 30 min

Cable Routing

48V

12V

CAN

Phase wires to motors

8-10 AWG

14-18 AWG

22 AWG twisted
Figure 21: Keep power, 12V, and signal cables separated.

Cable Management:
- Bundle power cables together (red/black)
- Bundle CAN cables separately (twisted pair)
- Use split loom or spiral wrap for protection
- Zip tie to frame at regular intervals
- Leave service loops near connectors

Cable Separation:
- Keep CAN bus away from motor phase wires (EMI)
- Cross power and signal cables at 90° angles
- Don’t run cables over hot components

ℹ NOTE Messy wiring works for BVR0 prototyping. But label everything. Future you will appreciate it.

## Drivetrain

The BVR0 uses skid-steer drive: four independent hub motors, one in each wheel. To turn, the left and right sides spin at different speeds (or opposite directions). It’s the same principle as a tank or a Roomba.

Hub motors eliminate chains, belts, gearboxes, and axles. The motor is the wheel. This means fewer parts, less maintenance, and no drivetrain to align. The tradeoff is that hub motors are heavier than outrunner motors with belt drive, but for a utility rover that’s not a problem.

The motors we use are 350W hoverboard motors. They’re mass-produced, cheap (around $85 each), and rated for exactly the kind of abuse a sidewalk rover will see.

## Direct Frame Mounting

Mount hub motors directly to frame | 30 min

The BVR0 keeps things simple: the hub motors bolt directly to the 2020 aluminum extrusion frame. No brackets, no adapters. The motor’s flat mounting face sits against the extrusion, and M5 bolts pass through into T-nuts in the channel.

SIDE VIEW

Bolt pattern

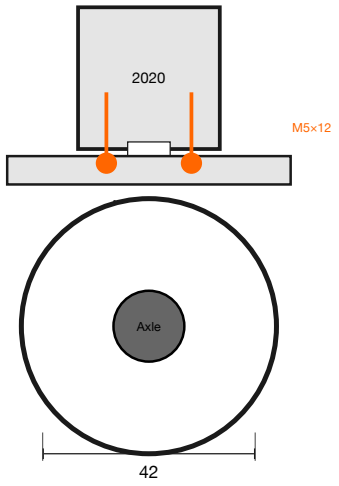
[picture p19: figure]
Motor face; Axle

Figure 22: Hub motor mounts directly to extrusion. No bracket required.

Mounting Procedure:

1. Slide 2× drop-in T-nuts into the extrusion channel at each wheel position
2. Position hub motor with mounting face flat against extrusion
3. Align motor’s 42mm bolt pattern with T-nuts
4. Insert M5×12 bolts through motor mounting holes into T-nuts
5. Hand-tighten, then torque to 4 Nm

Motor Positions:

Mount motors at frame corners, centered on each side rail. The exact position isn’t critical: the T-slot system allows adjustment.

Location | Rail
Front Left | Left side rail
Front Right | Right side rail
Rear Left | Left side rail
Rear Right | Right side rail

Hardware Per Motor:
- 2× M5×12 button head bolt
- 2× M5 drop-in T-nut

Standard 6.5″ hoverboard motors have a 42mm square bolt pattern with M5 threads.

ℹ NOTE The 42mm hole pattern fits standard 6.5″ hoverboard hub motors. Some motors may have different patterns: verify before ordering.

“We learned this the hard way:” We originally planned custom brackets. Then we realized the motor face sits flat against the extrusion perfectly. Sometimes the simplest solution is no solution at all.

## Hub Motor Installation

Install and wire hub motors | 20 min

1

2

3

T-nuts in channel

Extrusion

M5×12 ×2

Axle | Hub Motor Phase wires

Figure 23: Motor installation sequence. Wheels come pre-mounted on hub motors.

Installation Steps:

1. Position T-nuts in extrusion channel at wheel location
2. Align motor mounting holes with T-nut positions
3. Insert M5×12 bolts through motor into T-nuts
4. Hand-thread first, then tighten to 4 Nm
5. Route phase wires toward electronics bay
6. Secure wires with cable ties (leave slack for service)

⚠ WARNING Do not pinch phase wires between motor and frame. Route wires away from mounting surface before tightening.

“We learned this the hard way:” Hand-thread every bolt first before using a driver. Cross-threading an M5 into aluminum is easy to do and hard to fix.

## Wheel Alignment

Check and adjust wheel alignment | 15 min
d1 | d2
d1 = d2 ± 2mm at front and rear
Figure 24: String alignment method. Stretch strings parallel to frame sides.

Alignment Procedure:

1. Stretch two parallel strings along frame sides
2. Measure gap from string to front wheel edge
3. Measure gap from string to rear wheel edge
4. Gaps should be equal (±2mm) on each side
5. If not equal: loosen motor bolts, slide motor in T-slot, re-tighten

Common Issues:

Symptom | Cause
Fix | Rover pulls left
Right wheels toe-in | Slide right motors outward
Rover pulls right | Left wheels toe-in
Slide left motors outward | Excessive tire wear
Wheels not parallel | Realign all motors
Vibration at speed | Wheel out of round

Replace tire or motor ℹ NOTE The T-slot mounting makes alignment adjustable. This is one advantage of the direct-mount approach: loosen two bolts, slide, retighten.

## Power System

The rover runs on 48V nominal (13S lithium). This voltage is high enough to be efficient (less current means thinner wires and less heat) but low enough to avoid the regulatory complexity of “high voltage” systems.

BVR0 keeps the power system as simple as possible: battery → distribution bus → loads. The battery’s integrated BMS handles overcurrent and undervoltage protection. No separate inline fuses.

Respect the battery. A 48V 20Ah pack stores nearly 1 kWh of energy. That’s enough to weld metal if shorted, or start a fire if punctured. The safety section covers handling in detail.

ℹ NOTE BVR0 has an E-stop on the sensor mast but no inline fuse. The E-stop cuts power to all motors. BVR1 adds fuses and a relay-based e-stop with watchdog.

## Battery Mounting

Mount downtube battery to frame | 15 min

BVR0 uses an off-the-shelf 48V downtube-style e-bike battery. These batteries have an integrated mounting system: a bracket bolts to the frame, and the battery slides in and locks. No custom fabrication required.

SIDE VIEW

Central spine (2020)

Mounting rail

48V 20Ah

Downtube battery

Key lock | XT60 | XT60

~400mm
Figure 25: Downtube battery slides onto rail mounted to central 2020 spine.

Battery Requirements:
- 48V nominal (13S lithium)
- 15-20Ah capacity
- Downtube/bottle mount style
- Integrated BMS
- XT60 or similar output connector

Common sources:
- Unit Pack Power (AliExpress)
- Luna Cycle
- EM3ev

Mounting:
- Battery rail bolts directly to 2020 T-slot
- Use M5 bolts + T-nuts (2-4 per rail)
- Rail position: center of frame, lengthwise
- Battery slides in from one end, locks with key

Why downtube? Off-the-shelf, replaceable, keyed lock, integrated BMS, weather-resistant housing.

ℹ NOTE No custom battery tray needed. The downtube battery’s integrated mounting system is purpose-built for this. One less custom part.

## Safety Considerations

BVR0 has a physical E-stop button on the sensor mast and relies on the battery’s BMS for overcurrent protection. This is sufficient for prototype testing and supervised operation.

What BVR0 has:
- E-stop button (physical kill on mast)
- BMS overcurrent protection ( 60-100A)
- BMS undervoltage cutoff
- BMS short circuit protection
- Cell balancing

What BVR1 adds:
- Inline fuse (wire protection)
- E-stop relay (software-controlled kill)
- Watchdog timer (auto-stop on software crash)
- Headlights and tail lights

Emergency Shutdown (BVR0):
1. Press E-stop button on sensor mast (cuts power to motors)
2. Or: remove battery key and slide battery off rail
3. Or: disconnect XT60 at battery output

ℹ NOTE The E-stop button is wired directly in the motor power path. Pressing it immediately cuts power to all VESCs. No software required.

## DC-DC Converter

Install voltage regulator | 10 min

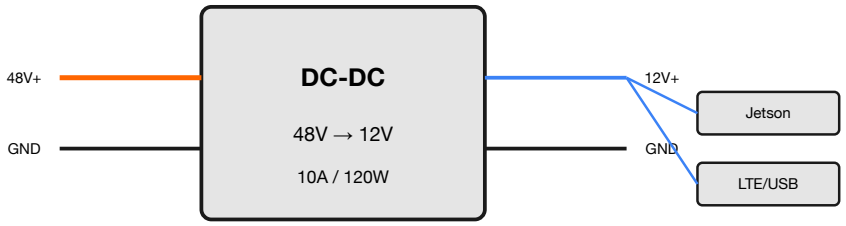
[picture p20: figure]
GND; Jetson; LTE/USB

Figure 26: DC-DC powers all 12V devices from the 48V main bus.

Specifications:

Parameter | Value
Input voltage | 36-60V (fits 13S LiPo range)
Output voltage | 12V regulated
Output current | 10A continuous
Efficiency | >90%
Mounting | M3 holes, heatsink on bottom

12V Load Budget:

Device | Current
Jetson Orin NX | 5A peak, 3A average
LTE modem | 1A
USB hub | 0.5A
Accessories | 1A reserve
Total | 6A typical, 10A max

## Power Distribution

Wire power bus | 30 min

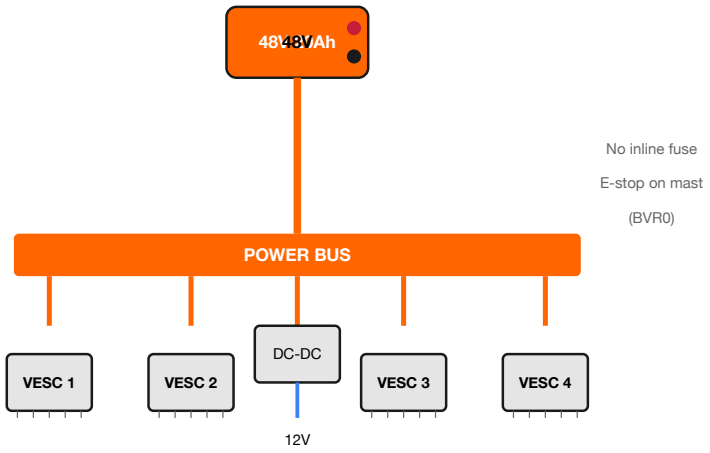
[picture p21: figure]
POWER BUS; VESC 1; VESC 2; VESC 3; VESC 4; No inline fuse; E-stop on mast; (BVR0)

Figure 27: BVR0 power topology: battery direct to bus. Simple but minimal protection.

Bus Options:

Splitter Cable (BVR0):
- XT60 to 5× XT60 (or solder joints)
- Simple, no fabrication
- Higher resistance, less tidy

Bus Bar (BVR1):
- Solid copper bar with tapped holes
- Clean, low resistance
- Integrates fuse and e-stop relay

## Electronics

The electronics are the nervous system: motor controllers that translate commands into wheel motion, a compute module that runs the autonomy stack, and a CAN bus that ties everything together.

We use VESC motor controllers because they’re open-source, powerful, and have a decade of real-world use in electric skateboards and robotics. The Jetson Orin NX handles perception and planning. It’s overkill for teleoperation, but essential for autonomous operation.

## VESC Mounting

Mount motor controllers | 20 min

VESC 6.7

60V 100A

Heatsink (face up)

48V+

GND

Phase A

Phase B

Phase C

CAN

M3 standoffs (6-10mm)
Figure 28: VESC mounted on standoffs for airflow. Heatsink faces up.

Mounting:
- M3×6 standoffs at all 4 corners
- M3×8 bolts through plate into standoffs
- Thermal pad between VESC and plate (optional, for heat transfer)

Power Connections:
- 10 AWG wire for 48V input
- XT60 connectors recommended
- Keep power wires short

⚡ COMMON MISTAKE VESCs generate serious heat under load. Without standoffs for airflow, thermal throttling kicks in after 3 minutes of hard driving.

## VESC Configuration

Set CAN IDs and motor parameters | 10 min per VESC

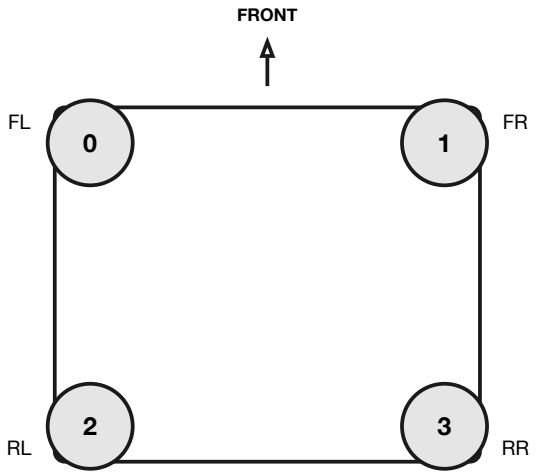
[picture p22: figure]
FRONT

Figure 29: CAN ID assignment. ID 0-3 for wheels, ID 10+ for tools.

VESC Tool Configuration:

Parameter | Value
Controller ID | 0, 1, 2, 3 (unique per VESC)
CAN Mode | VESC
CAN Baud Rate | CAN_500K
Send CAN Status | Enabled
CAN Status Rate | 50 Hz
Motor Type | BLDC or FOC (depends on motor)
Current Limit | 30A (per motor)

Motor Detection:

1. Connect VESC to computer via USB
2. Open VESC Tool
3. Run Motor Detection wizard
4. Save configuration to VESC
5. Disconnect USB, connect CAN

## Jetson Mounting

Install compute module | 15 min

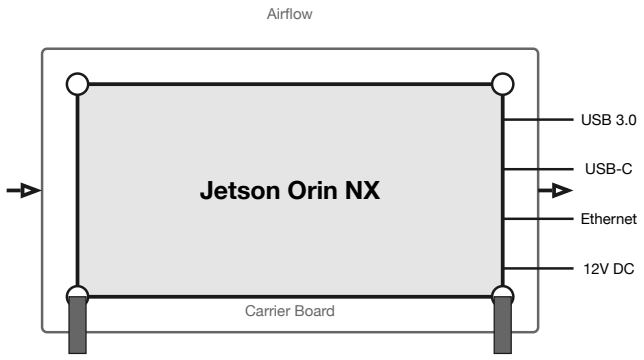
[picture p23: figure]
Jetson Orin NX; Carrier Board; USB 3.0; USB-C; Ethernet; Airflow

Figure 30: Jetson mounted on standoffs. Ensure airflow around heatsink.

Connections:

Port | Connection
CAN pins | CAN transceiver module
USB 3.0 | USB hub (camera, LTE)
12V DC | From DC-DC converter
GPIO | Not used (e-stop is hardwired)

Software:
- JetPack 6.0 or later
- bvrd daemon (auto-start on boot)
- Insta360 SDK for camera

Jetson Setup:

# Flash JetPack 6.0 using SDK Manager on host PC # After boot, install dependencies:

sudo apt update && sudo apt install -y can-utils pip install pyserial

# Clone firmware repo

git clone https: /github.com/muni-works/muni cd muni/bvr/firmware

# Build and install bvrd

cargo build -release
sudo cp target/release/bvrd /usr/local/bin/

sudo cp config/bvrd.service /etc/systemd/system/ sudo systemctl enable bvrd

Full setup instructions at github.com/muni-works/muni. (https://github.com/muni-works/muni/blob/main/bvr/firmware/README.md)

## GPIO Pinout

Reference: GPIO connections | 5 min

BVR0 uses minimal GPIO: just the CAN interface on the carrier board. The E-stop is wired directly in the power path (not relay-controlled). BVR1 adds GPIO-controlled e-stop relay and watchdog.

40-Pin Header (pins 1-20)

1 | 2
3 | 4
5 | 6
7 | 8
9 | 10
11 | 12
13 | 14
15 | 16
17 | 18
19 | 20

3.3V

GND

5V

BVR0: No GPIO used. CAN via carrier board.
Figure 31: GPIO header reference. BVR0 uses carrier board CAN, not GPIO.

BVR0 GPIO Usage:

BVR0 doesn’t use any GPIO pins directly. The CAN bus is provided by the carrier board’s dedicated CAN controller (not bit-banged GPIO).

Pin | Function
BVR0 | BVR1
1 | 3.3V
Unused | Status LED
2 | 5V
Unused | Unused
6 | GND
Unused | E-Stop ground
32 | GPIO12
Unused | E-Stop relay

ℹ NOTE BVR1 adds e-stop relay on GPIO12. See BVR1 manual for wiring details. The relay is normally-open: GPIO LOW = motors disabled (fail-safe).

## CAN Transceiver

Connect CAN bus interface | 10 min

The Jetson carrier board (Seeed reComputer J401 or similar) has CAN controller pins exposed. A CAN transceiver module converts these logic-level signals to the differential CAN bus.

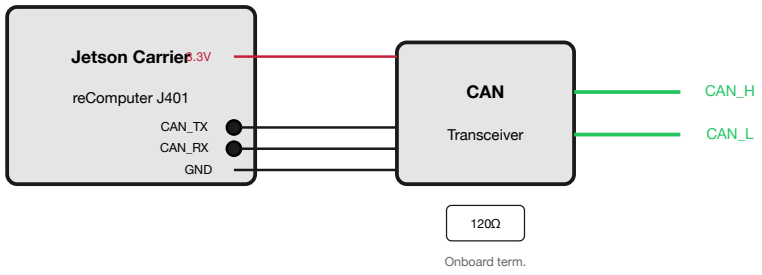
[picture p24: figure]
Jetson Carrier; reComputer J401; CAN_TX; CAN_RX; CAN; Transceiver; CAN_H; CAN_L; GND; Onboard term.

Figure 32: CAN transceiver connects carrier board CAN pins to differential bus.

Transceiver Modules:
- Waveshare SN65HVD230 module
- Any 3.3V CAN transceiver breakout
- Often included on carrier board (check your model)

Wiring:

Carrier Pin | Transceiver
Notes | CAN_TX
TXD | Logic level out
CAN_RX | RXD
Logic level in | 3.3V
VCC | Power
GND | GND

Common ground

Configuration:

# Enable CAN interface (may vary by carrier board) sudo modprobe mttcan

sudo ip link set can0 type can bitrate 500000 sudo ip link set can0 up

# Test with candump

candump can0

Termination:
- Most transceiver modules have onboard 120Ω termination
- CAN bus needs exactly 2 termination resistors (one at each end)
- If transceiver is at bus end: enable termination
- Verify: measure 60Ω across CAN_H/CAN_L (two 120Ω in parallel)

⚡ COMMON MISTAKE The reComputer carrier uses the Jetson’s native CAN controller (mttcan driver), not a USB adapter. Check your carrier’s pinout for CAN_TX/CAN_RX locations.

## Sensor Mast

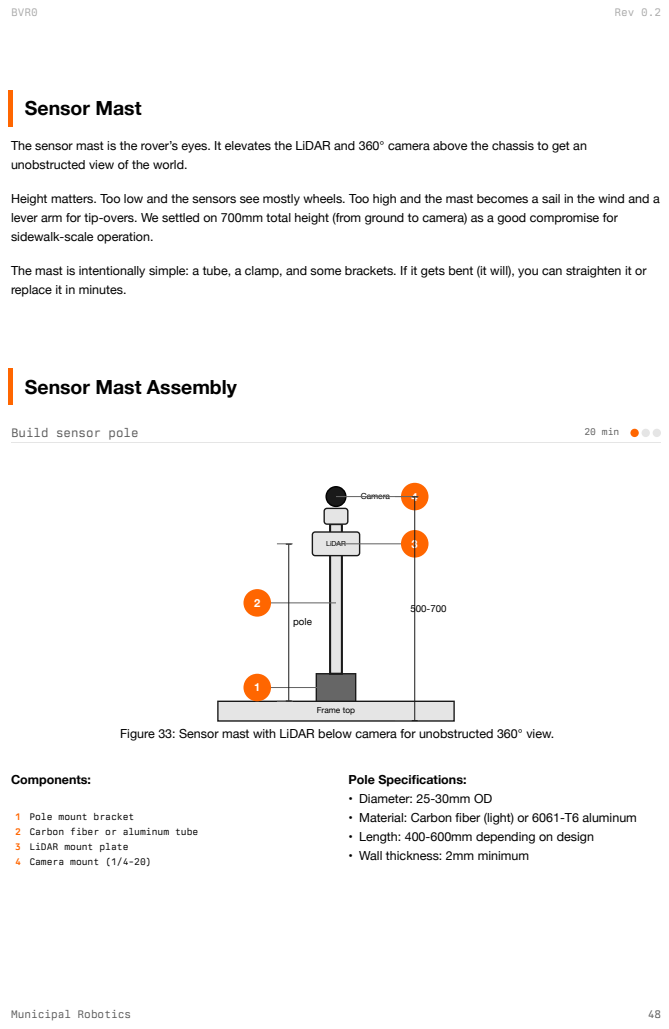
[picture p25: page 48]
Build sensor pole; 20 min; Frame top; LiDAR; Camera; pole; Components:

The sensor mast is the rover’s eyes. It elevates the LiDAR and 360° camera above the chassis to get an
unobstructed view of the world.

Height matters. Too low and the sensors see mostly wheels. Too high and the mast becomes a sail in the wind and a
lever arm for tip-overs. We settled on 700mm total height (from ground to camera) as a good compromise for
sidewalk-scale operation.

The mast is intentionally simple: a tube, a clamp, and some brackets. If it gets bent (it will), you can straighten it or
replace it in minutes.

Sensor Mast Assembly

Figure 33: Sensor mast with LiDAR below camera for unobstructed 360° view.

Pole Specifications:
• Diameter: 25-30mm OD
• Material: Carbon fiber (light) or 6061-T6 aluminum
• Length: 400-600mm depending on design
• Wall thickness: 2mm minimum

1 Pole mount bracket
2 Carbon fiber or aluminum tube
3 LiDAR mount plate
4 Camera mount (1/4-20)

## LiDAR Mounting

Mount LiDAR sensor | 15 min

Figure 34: Top view: full 360° sensing

SIDE VIEW

Mid-360 | Cable

Bracket

Pole
Figure 35: Side view: cable routes down

Installation:

1. Attach LiDAR to mount plate with M3 bolts
2. Level the mount plate (use spirit level)
3. Secure mount plate to pole with hose clamps or bolts
4. Route cable inside pole or along outside with ties
5. Connect to Jetson via Ethernet

Orientation:
- LiDAR “front” should face rover front
- Ensure level within ±1°
- No obstructions in 360° view

## Camera Mounting

Mount 360° camera | 10 min

X4

Lens (front)

Lens (rear)

1/4-20 mount

Adapter

360° × 180°

Figure 36: Camera at mast top. Dual lenses capture full spherical view.

Mount Options:
- 1/4-20 threaded insert in pole top cap
- GoPro-style mount adapter
- Custom 3D-printed adapter

Cable Routing:
- USB-C cable to Jetson
- Route inside pole if possible
- Secure with cable ties
- Leave strain relief loop at camera

Camera Settings:

Setting | Value
Mode | Live streaming (H.265)
Resolution | 4K or 5.7K
Frame rate | 30 fps
Stabilization | FlowState (on)

## Wiring

Wiring is where builds go wrong. A loose connection causes intermittent failures. A reversed polarity destroys components. A pinched wire works fine until it doesn’t.

Take your time here. Label every wire. Double-check polarity before applying power. Use the correct gauge wire for the current it carries. The extra hour spent on clean wiring saves days of debugging later.

The schematic on the next page shows the complete system. Study it before you start, and refer back to it often.

## System Wiring Schematic

Reference: complete wiring diagram | reference

POWER

COMPUTE

Legend

48V Power

12V Power

CAN Bus

Signal/USB
Figure 37: Complete system wiring. Power flows left, compute/sensors right.

## CAN Bus Wiring

Wire CAN bus network | 30 min

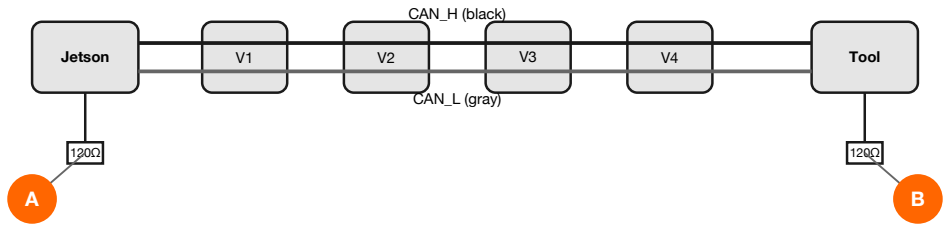
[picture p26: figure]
Jetson; Tool; CAN_H (black); CAN_L (gray)

Figure 38: CAN bus with 120Ω termination at each end (A and B).

Wiring Rules:

- Use twisted pair wire (22 AWG)
- CAN_H to CAN_H, CAN_L to CAN_L at each device
- Maximum total bus length: 40m at 500K baud
- Exactly 2 termination resistors (one at each end)
- Keep CAN wires away from motor phase wires

JST Connector Pinout:

Pin | Signal
Color (typical) | 1
GND | Black
2 | CAN_L
Gray or White | 3
CAN_H | Orange or Yellow
4 | +5V (optional)

Red

## Motor Phase Wiring

Connect motor phase wires | 15 min per motor

VESC

A (Blue)

B (Green)

C (Yellow)

4mm bullets

Motor

Figure 39: Phase wires connect VESC to motor via bullet connectors.

Connection Notes:

- Motor wire colors may not match VESC colors
- If motor spins wrong direction: swap any two phase wires
- Use 4mm gold bullet connectors (60A rated)
- Solder connections, use heat shrink
- Keep phase wires away from signal wires (EMI)

Wire Lengths:

Motor Position | Approx. Length
Front Left | 400mm
Front Right | 500mm
Rear Left | 300mm
Rear Right | 400mm

ℹ NOTE Add 50mm extra for service loops. Too tight = strain on connectors.

⚡ COMMON MISTAKE Phase wire order doesn’t matter for direction (any two can be swapped). But inconsistent colors across all 4 motors makes troubleshooting a nightmare. Pick a convention and stick to it.

## Signal Wiring

Route USB and signal cables | 20 min

Jetson

Camera

LTE

USB Hub

CAN

LiDAR

Figure 40: Jetson connections. USB for peripherals, CAN for VESCs, Ethernet for LiDAR.

Port Allocation:

Port | Device
Cable | CAN pins
CAN transceiver → VESCs | JST → bus
USB 3.0 1 | USB Hub
USB-A to hub | Hub Port 1
Insta360 X4 | USB-C
Hub Port 2 | LTE modem
USB-A | Ethernet
Livox LiDAR | RJ45

E-Stop (BVR0):
- Hardwired switch on sensor mast
- Wired in series with motor power
- No GPIO control (direct disconnect)

## Cable Management

Secure and organize all wiring | 30 min

Frame interior (top view)

48V

12V

CAN

USB

sep

tie | tie | tie | tie

Figure 41: Route power and signal cables separately. Secure every 150mm.

Routing Rules:

- Separate power (48V) from signals by at least 25mm
- CAN bus twisted pair reduces interference
- Use cable ties every 100-150mm
- Leave service loops at connectors
- Label both ends of each cable

Cable Tie Points:
- Frame corners
- Near each connector
- Before/after bends
- At entry to electronics bay

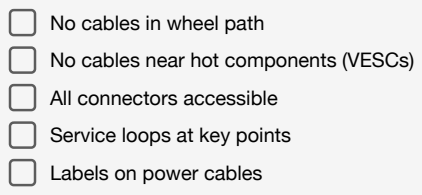
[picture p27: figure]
No cables in wheel path; No cables near hot components (VESCs); All connectors accessible; Service loops at key points; Labels on power cables

“We learned this the hard way:” Beautiful cable management is great until you need to replace a VESC. Leave enough slack to pull components 10cm out for service without disconnecting everything upstream.

## Testing

This is the moment of truth. You’ve built the mechanical system, wired the electronics, and configured the software. Now you find out if it all works together.

Go slow. The pre-power checks exist because we’ve made every mistake in this section at least once. A reversed connector, a missed termination resistor, a VESC with the wrong ID, these are easy to fix before you apply power and much harder after.

The first power-up should be anticlimactic. If you smell burning, hear crackling, or see smoke: power off immediately. Something is wrong, and continuing will make it worse.

## Pre-Power Checks

Verify connections before first power-on | 10 min

Multimeter Tests

Continuity Tests (power OFF):

Test | Probe Points
Expected | 48V+ to GND
Battery connector pins | Open (no beep)
12V+ to GND | DC-DC output
Open (no beep) | CAN_H to CAN_L
CAN connector | 60Ω (two 120Ω in parallel)
Phase A to B | Motor connector

Low resistance (motor windings)

Visual Inspection:

No exposed wire or bare conductors

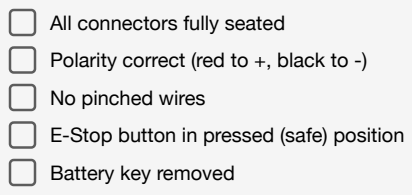
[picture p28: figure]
All connectors fully seated; Polarity correct (red to +, black to -); No pinched wires; Battery key removed

E-Stop button in pressed (safe) position

⚠ DANGER If any continuity test shows a short (beep) between power and ground, DO NOT APPLY POWER. Find and fix the short first.

## First Power-Up

Initial power-on sequence | 5 min

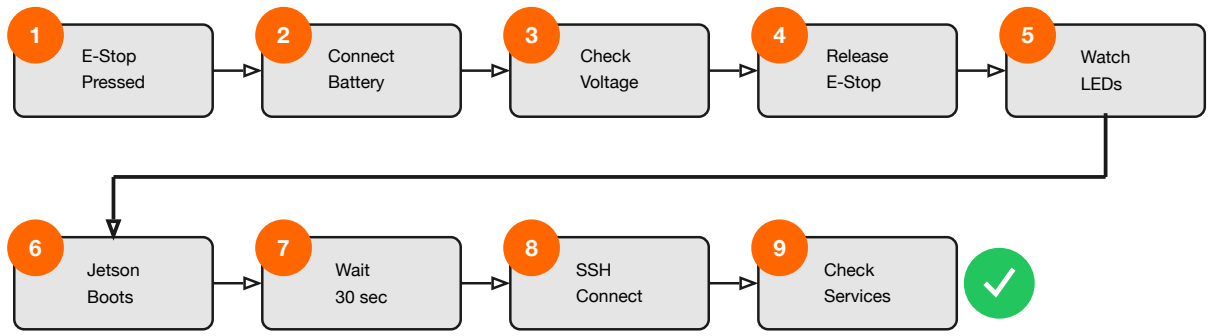
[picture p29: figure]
E-Stop; Pressed; Connect; Battery; Check; Voltage; Release; Watch; LEDs; Jetson; Boots; Wait; 30 sec; SSH; Services

What to Watch:

Indicator | Normal
Problem | VESC LEDs
Solid green | Red = fault, none = no power
Jetson LED | Solid then blinking
None = power issue | DC-DC LED
Green (if equipped) | None = input voltage issue
Smell | None
Burning = immediate power off | Sound
Quiet hum | Buzzing = loose connection

## VESC Configuration

Configure motor controllers using VESC Tool.

1. Connect laptop to VESC via USB
2. Open VESC Tool
3. Select serial port, click Connect

Motor Wizard:
1. Navigate to Motor → Motor Wizard
2. Select motor type (usually “Large outrunner”)
3. Run detection: VESC will spin motor briefly
4. Review detected parameters
5. Write configuration to VESC

CAN Configuration:
1. Navigate to App → CAN Status
2. Set unique Controller ID (0, 1, 2, 3)
3. Set CAN Baud to 500K
4. Enable “Send CAN Status”
5. Write configuration

Per-VESC Settings:

VESC | ID
Motor Direction | Front Left
0 | Forward = CCW
Front Right | 1
Forward = CW | Rear Left
2 | Forward = CCW
Rear Right | 3

Forward = CW

ℹ NOTE Left and right motors spin opposite directions for forward motion in skid-steer.

⚡ COMMON MISTAKE Swapping VESC IDs 0↔1 or 2↔3 makes the rover spin in circles instead of driving straight. The CAN ID diagram on the Quick Reference Card saves debugging time.

## Motor Testing

Verify motor response | 10 min

⚠ WARNING Elevate rover so all wheels are off the ground before motor testing.

BVR0

CCW | CW

Blocks

Figure 44: Test with wheels elevated. Verify each motor spins correct direction.

Test Procedure:

1. Elevate rover on blocks (all wheels free)
2. Power on, release E-Stop
3. Connect controller
4. Command forward slowly: all wheels should spin “forward”
5. Command reverse: all wheels should spin “backward”
6. Command left turn: right wheels forward, left wheels backward
7. Test E-Stop: press button, verify immediate stop

Direction Fix: If a motor spins wrong direction, swap any two phase wires on that motor.

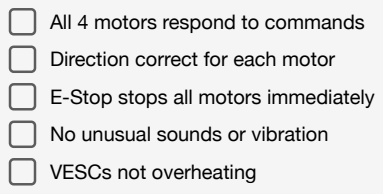
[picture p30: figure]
All 4 motors respond to commands; Direction correct for each motor; E-Stop stops all motors immediately; No unusual sounds or vibration; VESCs not overheating

“We learned this the hard way:” The first road test had the rover on flat ground. It took off at 2 m/s and hit a wall. Always test on blocks first, with throttle at minimum.

## Operation

Operating the rover is straightforward once it’s built and tested. The startup sequence takes about 3 minutes. Shutdown takes 1 minute. Most of that time is waiting for the Jetson to boot.

The key habit is consistency. Use the same startup sequence every time. Check the same indicators. Park in the same spot. Consistent routines catch problems early, when they’re small and easy to fix.

## Startup Procedure

Power on and connect | 3 min

Pre-flight
Checklist | 2 min

Connect
Battery | 5 sec

Wait for
Boot (30s) | 30 sec

Connect
Controller

10 sec

Verify
Telemetry | verify

Figure 45: Startup takes approximately 3 minutes.

Detailed Steps:

1. Pre-flight: Complete checklist on page 2
2. Battery: Connect XT90 (hear click). E-Stop should be pressed.
3. Boot: Release E-Stop. Wait for Jetson to boot (30s). VESC LEDs turn green.
4. Controller: Power on controller. Connect to operator station.
5. Telemetry: Verify video feed, voltage reading, and mode indicator.

ℹ NOTE Do not operate if telemetry shows errors or video feed is absent.

## Shutdown Procedure

Safe power-off sequence | 1 min

Return to
Home

Release
Controls

Press
E-Stop

Disconnect
Battery

Figure 46: Always press E-Stop before disconnecting battery.

Shutdown Checklist:

Rover parked in designated area

Controller set down / powered off

E-Stop button pressed (red button down)

Wait 5 seconds for Jetson to save state

Disconnect battery (pull XT90)

Store battery properly (50-60% charge for long storage)

⚠ WARNING Never disconnect battery while Jetson is running. This can corrupt the filesystem.

## Tool Attachment

Attach tools to chassis | 15 min

BVR0 uses direct bolt mounting for tools: no quick-release, no modular interface. Tools attach to the 2020 extrusion frame using T-nuts and bolts, just like everything else on the rover.

Bolt down

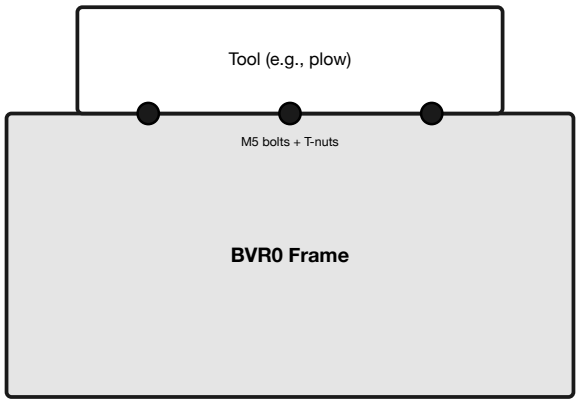
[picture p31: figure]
BVR0 Frame; Tool (e.g., plow); M5 bolts + T-nuts

Figure 47: Tool bolts directly to frame using T-slot hardware.

Attachment Procedure:

1. Power OFF rover (E-Stop pressed)
2. Position tool on frame, align with T-slots
3. Insert M5 bolts through tool mounting holes
4. Thread into T-nuts in frame extrusion
5. Tighten with 4mm hex key (hand-tight + 1/4 turn)
6. Connect power cable (if tool is powered)
7. Power ON rover

Removal:

1. Power OFF rover
2. Disconnect power cable first
3. Loosen M5 bolts
4. Lift tool off frame

ℹ NOTE BVR1 adds a quick-release rail system with electrical pass-through. BVR0 keeps it simple: bolts work.

## Safety

The BVR0 is a machine, and machines can hurt you. The hazards are real: spinning wheels that don’t care about fingers, a battery that can catch fire, a 30kg robot that can pin you against a wall.

None of this is meant to scare you. These hazards are manageable with basic awareness and respect for the machine. The safety protocols in this section come from experience (some of it painful). Follow them.

## Personal Protective Equipment

PPE requirements by task | reference
Task | Required PPE
Cutting extrusions | Safety glasses, work gloves
Soldering / wiring | Safety glasses, fume extraction
Battery handling | Insulated gloves, safety glasses
Motor testing | Safety glasses, hearing protection
Operation | None required (stay clear of rover)

Safe Operating Distance:
- Operator: minimum 2m from rover during teleop
- Bystanders: minimum 5m from operating rover
- During charging: check every 15 min, do not leave unattended

## Hazard Zones

Know the danger zones | reference

⚠ DANGER Stay clear of marked zones during operation. Serious injury possible.

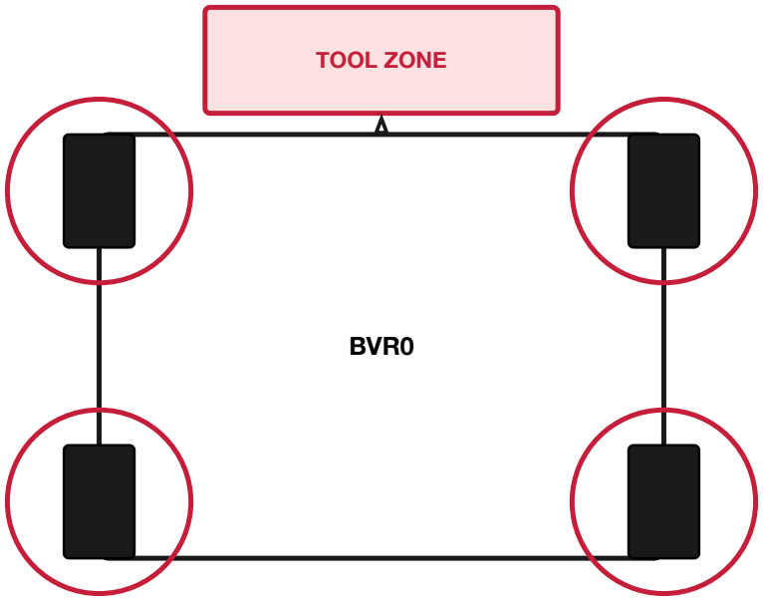
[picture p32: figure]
BVR0; TOOL ZONE

Pinch/Crush hazard | Tool operation zone

Figure 48: Keep hands, feet, and loose clothing clear of marked zones.

Hazard Types:

Zone | Hazard
Injury Type | Wheel areas
Rotating wheels, motor torque | Crush, pinch, friction burn
Tool zone | Rotating auger/blade
Laceration, amputation | Underside
50mm ground clearance | Crush if rover tips
Battery area | Electrical, thermal

Shock, burns

## Battery Safety

Handle lithium batteries safely | reference

⚠ WARNING Li-ion batteries can catch fire if damaged, punctured, or short-circuited.

DO

15-25°C | Store temp
50-60% | Storage charge
Inspect | Before each use

DON’T

No water | Keep dry
No puncture | Protect case
No fire | Never burn

Signs of Battery Damage:
- Swelling or bulging
- Unusual heat
- Hissing or venting
- Visible damage to case
- Reduced capacity

In Case of Battery Fire:

1. Evacuate the immediate area (minimum 10m / 30ft)
2. Call fire department: 911
3. If small and contained: use CO2 or ABC dry chemical extinguisher
4. If large or spreading: do not attempt to extinguish (let professionals handle)
5. Ventilate area (toxic fluoride fumes)
6. Water in large quantities can cool adjacent cells and prevent spread, but small amounts can make it worse

⚠ WARNING Li-ion fires re-ignite. Monitor for at least 1 hour after fire appears out. Do not move battery until cool.

⚠ DANGER Never attempt to charge a damaged battery. Dispose at authorized battery recycling facility (Call2Recycle, Best Buy, etc.).

## Firmware

The rover runs two firmware stacks: bvrd on the Jetson (the main brain), and embedded firmware on tool attachments (ESP32-based).

Most operators never need to touch firmware. It comes pre-flashed on shipped units, and updates are pushed over-the-air. This section is for those building from scratch or doing development work.

If you’re comfortable with Linux command lines and embedded toolchains, this will be familiar. If not, follow the steps exactly, and don’t skip the verification steps.

## Initial Jetson Setup

Flash and configure Jetson | 45 min

Full setup guide: github.com/muni-works/muni (https://github.com/muni-works/muni/blob/main/bvr/firmware/README.md)

### 1. Flash JetPack OS:

Download JetPack 6.0+ from NVIDIA. Flash using SDK Manager on Ubuntu host:

# On Ubuntu 20.04/22.04 host machine

sudo apt install nvidia-sdk-manager sdkmanager # GUI will launch

Select “Jetson Orin NX” and JetPack 6.0. Follow prompts to flash.

### 2. First Boot Configuration:

# Set hostname

sudo hostnamectl set-hostname bvr0

# Create muni user (if not done during setup) sudo adduser muni

sudo usermod -aG sudo,dialout,video muni

# Enable SSH

sudo systemctl enable ssh

### 3. Install Dependencies:

sudo apt update && sudo apt upgrade -y
sudo apt install -y can-utils build-essential \ libclang-dev pkg-config libssl-dev

# Install Rust

curl -proto '=https' -tlsv1.2 -sSf \
https: /sh.rustup.rs | sh
source ~/.cargo/env

## CAN Bus Setup

Configure CAN interface | 10 min

### 1. Load CAN Modules:

# Add to /etc/modules-load.d/can.conf

echo "can" | sudo tee /etc/modules-load.d/can.conf
echo "can_raw" | sudo tee -a /etc/modules-load.d/can.conf
echo "slcan" | sudo tee -a /etc/modules-load.d/can.conf

### 2. Create Startup Service:

Create /etc/systemd/system/can.service:

[Unit]
Description=CAN Bus Interface After=network.target

[Service]
Type=oneshot
RemainAfterExit=yes
ExecStart=/sbin/ip link set can0 type can bitrate 500000 ExecStart=/sbin/ip link set can0 up
ExecStop=/sbin/ip link set can0 down

[Install]
WantedBy=multi-user.target

sudo systemctl enable can.service sudo systemctl start can.service

### 3. Verify CAN:

# Should show can0 interface

ip link show can0

# Monitor CAN traffic (VESCs should send status) candump can0

## LiDAR Setup

Configure LiDAR network | 15 min

### 1. Network Configuration:

The Mid-360 uses a static IP. Configure the Jetson Ethernet:

# Add to /etc/netplan/01-lidar.yaml

network:
version: 2
ethernets:
eth0:
addresses:
- 192.168.1.50/24
routes:
- to: 192.168.1.0/24
via: 192.168.1.1

sudo netplan apply

### 2. LiDAR Default Settings:

Parameter | Value
LiDAR IP | 192.168.1.1xx (xx = last 2 of serial)
Host IP | 192.168.1.50
Data Port | 56000
Command Port | 56001

### 3. Test Connection:

# Ping LiDAR (replace with your unit's IP) ping 192.168.1.100

# Install Livox SDK2 for testing

git clone https: /github.com/Livox-SDK/Livox-SDK2 cd Livox-SDK2 && mkdir build && cd build
cmake . && make -j4

## bvrd Installation

Install rover daemon | 15 min

### 1. Clone Repository:

cd /opt
sudo mkdir muni && sudo chown muni:muni muni git clone https: /github.com/muni-works/bvr.git cd bvr/firmware

### 2. Build:

cargo build -release
sudo cp target/release/bvrd /opt/muni/bin/

### 3. Install Service:

sudo cp config/bvrd.service /etc/systemd/system/ sudo systemctl daemon-reload
sudo systemctl enable bvrd
sudo systemctl start bvrd

### 4. Verify:

sudo systemctl status bvrd journalctl -u bvrd -f

## Firmware Overview

The rover uses two main firmware components.

Jetson

bvrd

Attachment

ESP32

USB

Drive, sensors,
depot link

LEDs, tools,
actuators
Figure 50: Firmware architecture: Jetson runs bvrd, attachments run on ESP32.

bvrd (Jetson)
- Main rover daemon
- Motor control via CAN
- Sensor fusion
- Depot communication
- Attachment discovery

Attachment (ESP32)
- Tool-specific firmware
- LED control
- Local sensors
- SLCAN protocol
- Status heartbeat

## Updating bvrd

Deploy firmware updates | 5 min

Prerequisites:
- SSH access to Jetson
- Rust toolchain with aarch64 target

Build and Deploy:

# On development machine

cd bvr/firmware
cargo build -release -target aarch64-unknown-linux-gnu

# Copy to Jetson

scp target/aarch64-unknown-linux-gnu/release/bvrd \ muni@<jetson-ip>:/opt/muni/bin/

# On Jetson - restart service

ssh muni@<jetson-ip>
sudo systemctl restart bvrd

Verify:

# Check service status

sudo systemctl status bvrd

# View logs

journalctl -u bvrd -f

## Updating Attachment Firmware

Flash ESP32 attachments | 10 min

Prerequisites:
- ESP32 Rust toolchain (espup install)
- espflash tool installed
- Attachment connected via USB

Build:

cd mcu/bins/esp32s3
source ~/export-esp.sh
cargo build -release

Flash:

espflash flash \
-ignore-app-descriptor \
-partition-table partitions.csv \
-bootloader bootloader.bin \
-min-chip-rev 0.0 \
target/xtensa-esp32s3-none-elf/release/mcu-esp32s3

Monitor Serial Output:

espflash monitor
# Or: screen /dev/cu.usbserial-0001 115200

If flash fails:
1. Unplug USB
2. Hold BOOT button
3. Plug in USB (keep holding)
4. Release after 2 seconds
5. Retry flash command

## Attachment Protocol

Attachments communicate via SLCAN (CAN-over-serial).

O\r

Open

t2010\r

Identify

t2024...

Response

t2008...

Heartbeat
Figure 51: Discovery flow: open channel, identify, then heartbeat begins.

CAN Message IDs (Attachment Slot 0):

ID | Direction
Purpose | 0x200
Attach → Host | Heartbeat (1Hz)
0x201 | Host → Attach
Identify request | 0x202
Attach → Host | Identity response
0x203 | Host → Attach
Command | 0x204
Attach → Host | Acknowledgment

Text Commands (for debugging):

led 255,0,0 | # Set LED red
cycle | # Rainbow cycle mode
state running # Set state
help | # Show commands

## Maintenance

A well-maintained rover is a reliable rover. The maintenance tasks are simple: clean it, inspect it, keep the bolts tight and the battery healthy.

The schedule below is based on real-world operation in Cleveland conditions (salt, snow, mud, temperature swings). If you operate in a milder environment, you can extend the intervals. If you’re running daily in harsh conditions, shorten them.

## Maintenance Schedule

Preventive maintenance overview | varies

Weekly

Light clean

Monthly

Inspect

Seasonal

Full service

Weekly
- Clean wheels and chassis
- Wipe camera lens
- Wipe LiDAR lens
- Check connector seating
- Verify wheel spin
- Test E-Stop function

Monthly
- Inspect all wiring
- Check bolt torque
- Clean electrical contacts
- Check battery health
- Update firmware
- Review error logs

Seasonal
- Full electrical inspection
- Check wheel bearings
- Replace worn tires
- Deep clean chassis
- Calibrate sensors
- Battery capacity test

## Troubleshooting

Diagnose common issues | varies
Symptom | Likely Cause
Solution | Won’t power on
Battery disconnect | Check XT90 connection, verify fuse
No video feed | Camera USB
Reconnect camera, check USB hub power | Motor not responding
CAN wiring | Check CAN connections, verify VESC ID
Erratic movement | VESC ID mismatch
Verify IDs match wheel positions | E-Stop won’t release
Button stuck | Check relay wiring, verify mechanism
Overheating | Ventilation blocked
Clean vents, reduce load | Poor LTE signal
Antenna position | Reposition antenna, check SIM
Battery dies quickly | Battery age
Check cell balance, replace if needed | Jerky motion
Motor calibration | Re-run VESC motor detection
Drift to one side | Wheel alignment

Re-align motor brackets

Diagnostic Commands:

# Check system status

bvr status

# List CAN devices

bvr can scan

# Test individual motor

bvr motor test <id>

# View recent logs

journalctl -u bvrd -n 100
- Troubleshooting Walkthrough (https://muni.works/docs/troubleshooting)

## Storage

Store rover properly | 5 min

50-60%

Battery charge

### Disconnect

Unplug battery

15-25°C

Temperature

Short-Term Storage (< 1 week):

Long-Term Storage (> 1 week):

Charge battery to 50-60%

Disconnect battery completely

Clean chassis and wheels

Cover camera and LiDAR lenses

Store in dry location (15-25°C)

Check battery monthly (recharge if < 40%)

Returning from Storage:

1. Inspect for moisture, corrosion, pest damage
2. Charge battery fully
3. Run pre-flight checklist
4. Test all functions before field use

## Bill of Materials

This is everything you need to build one BVR0 from scratch. Prices are approximate as of late 2025 and vary by region and vendor.

A few notes on sourcing: the expensive items (Jetson, LiDAR, camera) are worth buying from authorized distributors for warranty support. The commodity items (extrusions, fasteners, wire) can come from anywhere. The hub motors are sourced from AliExpress because that’s where they’re cheapest; allow 2-3 weeks for shipping.

The total cost ( $4,200) is roughly split: one-third mechanical, one-third power/drive, one-third compute/sensors. If you’re building multiple units, the mechanical and power costs drop significantly with bulk ordering.

Structural

Part | Qty | Unit | Total | Source
2020 Aluminum Extrusion, 1m | 6 | $8 | $48 | Amazon / 8020.net
90° Corner Bracket | 16 | $1.50 | $24 | Amazon
M5×10 Button Head Bolt | 64 | $0.15 | $10 | McMaster
M5 T-Nut (drop-in) | 64 | $0.20 | $13 | Amazon
M5 T-Nut (pre-load) | 32 | $0.15 | $5 | Amazon
25mm Aluminum Tube (mast) | 1 | $15 | $15 | Local metal supplier

Drivetrain

Part | Qty | Unit | Total | Source
Hub Motor 350W 48V | 4 | $85 | $340 | AliExpress / ODrive
VESC 6.7 (Flipsky) | 4 | $120 | $480 | Flipsky
M5×12 Button Head Bolt | 8 | $0.15 | $2 | McMaster
4mm Bullet Connectors | 24 | $0.50 | $12 | Amazon

Power

Part | Qty | Unit | Total | Source

48V 20Ah Downtube Battery | 1 | $400 | $400 | Unit Pack Power / Luna
E-Stop Mushroom Button | 1 | $15 | $15 | Amazon
XT60 Connector Pair | 8 | $2 | $16 | Amazon
DC-DC 48V→12V 10A | 1 | $35 | $35 | Amazon
10 AWG Silicone Wire (red) | 3m | $2/m | $6 | Amazon
10 AWG Silicone Wire (black) | 3m | $2/m | $6 | Amazon

Electronics

Part | Qty | Unit | Total | Source
Jetson Orin NX 16GB | 1 | $600 | $600 | Seeed / Arrow
Carrier Board w/ CAN | 1 | $130 | $130 | Seeed / Waveshare
USB 3.0 Hub (powered) | 1 | $25 | $25 | Amazon
LTE Modem (USB) | 1 | $50 | $50 | Amazon
22 AWG Wire (CAN, assorted) | 10m | $0.50/m | $5 | Amazon
JST-XH 4-pin Connector | 10 | $0.50 | $5 | Amazon
Electrical Tape | 2 rolls | $3 | $6 | Amazon
Velcro Strips | 1 pack | $8 | $8 | Amazon

Sensors

Part | Qty | Unit | Total | Source
Livox Mid-360 LiDAR | 1 | $1,000 | $1,000 | Livox
Insta360 X4 Camera | 1 | $500 | $500 | Insta360
RTK GPS Module (optional) | 1 | $200 | $200 | SparkFun

Miscellaneous

Part | Qty | Unit | Total | Source
Zip Ties (assorted) | 1 pack | $8 | $8 | Amazon
Heat Shrink Tubing | 1 kit | $12 | $12 | Amazon
Loctite 243 (blue) | 1 | $8 | $8 | Amazon
Dielectric Grease | 1 | $6 | $6 | Amazon
Cable Sleeve (split loom) | 5m | $1/m | $5 | Amazon

Subtotals

Structural | $115
Drivetrain | $834
Power | $478
Electronics | $829
Sensors | $1,700

## Total: $3,995

Excludes tools, shipping, and taxes. Prices vary by region and vendor.

Misc | $39

## Hardware Reference

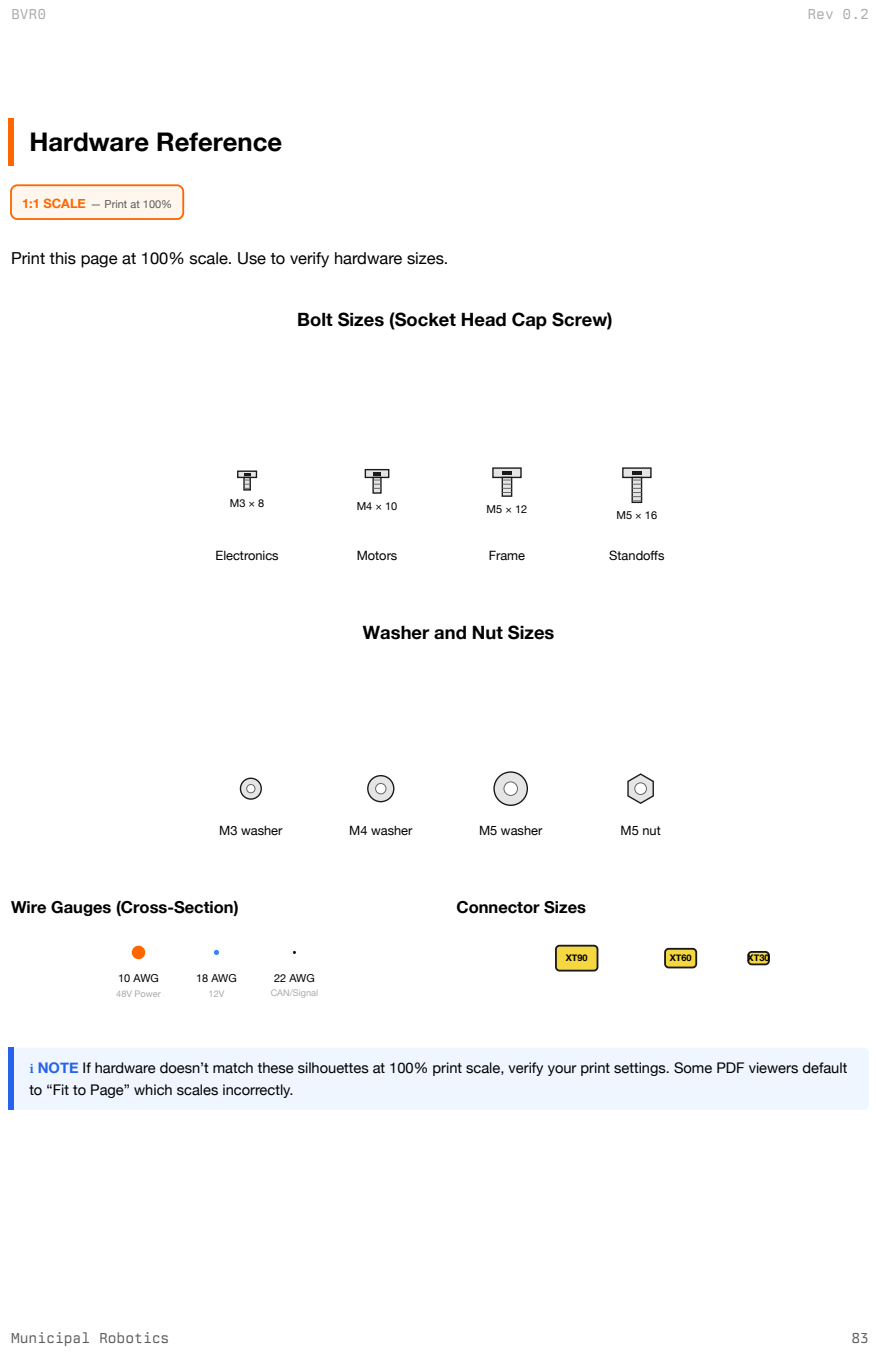
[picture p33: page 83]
Electronics; Motors; Frame; Standoffs; M3 washer; M4 washer; M5 washer; M5 nut; 10 AWG; 48V Power; 18 AWG; 22 AWG; CAN/Signal; Connector Sizes

1:1 SCALE — Print at 100%

Print this page at 100% scale. Use to verify hardware sizes.

Bolt Sizes (Socket Head Cap Screw)

Washer and Nut Sizes

Wire Gauges (Cross-Section)

ℹ NOTE If hardware doesn’t match these silhouettes at 100% print scale, verify your print settings. Some PDF viewers default
to “Fit to Page” which scales incorrectly.

## Glossary

This manual uses a lot of acronyms and technical terms. If you encounter an unfamiliar term, check here first.

AWG American Wire Gauge. Lower numbers = thicker
wire. 10 AWG for power, 22 AWG for signals.

BLDC Brushless DC motor. Uses electronic commutation instead of brushes.

BVR Base Vectoring Rover. Muni’s first rover morphology.

CAN Controller Area Network. Industrial communication bus used for motor control.

CAN_H / CAN_L CAN High and CAN Low. Differential pair signals.

CCW / CW Counter-clockwise / Clockwise. Motor rotation direction.

DC-DC DC-DC converter. Steps voltage down (48V → 12V).

DT Connector Deutsch DT connector. Weatherproof automotive connector.

E-Stop Emergency Stop. Cuts power to motors immediately.

FOC Field-Oriented Control. Advanced motor control algorithm for smooth, efficient operation.

GPIO General Purpose Input/Output. Digital pins on the Jetson.

Hub Motor Motor integrated into the wheel hub. No external gears or chains.

Jetson NVIDIA Jetson. Embedded AI computer. BVR0 uses Orin NX.

LiDAR Light Detection and Ranging. Laser-based 3D sensor.

LiPo Lithium Polymer battery. High energy density, requires careful handling.

LTE Long-Term Evolution. Cellular data connection.

Nm Newton-meter. Unit of torque.

RTK Real-Time Kinematic. GPS correction for centimeter accuracy.

Skid-Steer Steering method where left and right sides drive at different speeds.

T-Nut Threaded nut that slides into aluminum extrusion T-slots.

Teleop Teleoperation. Remote control of the rover by a human operator.

Termination 120Ω resistor at CAN bus endpoints to prevent signal reflection.

VESC Vedder Electronic Speed Controller. Open-source motor controller.

XT Connector Amass XT series. Yellow power connectors (XT90, XT60, XT30).

## Index

Page numbers reference the first significant mention of each topic. See the Table of Contents for section-level navigation.

A
- Aluminum extrusion, 7-9
- AWG (wire gauge), 18

B
- Battery, 13-14, 28
- Battery safety, 28
- BOM (Bill of Materials), 30-31
- Bolts, torque values, 9

C
- Cable management, 21
- CAN bus, 17-18
- CAN IDs, 15
- Charging, 28
- Checklist, pre-flight, 2
- Connectors, 18-19
- Controls, 3
- Corner brackets, 8

D
- DC-DC converter, 14
- Diagnostics, 27
- Difficulty ratings, page headers

E
- E-Stop, 1, 23
- Electronics plate, 10
- Extrusions, cutting, 7

F
- First power-up, 22
- Firmware, 26
- Frame assembly, 8

G
- GPIO, 16
- Glossary, 32

H
- Hazard zones, 27
- Hub motors, 11

J
- Jetson mounting, 15

L
- LiDAR, 5

M
- Maintenance, 26
- Motor testing, 23
- Motor wiring, 19

P
- Phase wires, 19
- PPE, 27
- Power system, 13-14

Q
- Quick reference, 1-3

S
- Safety, 27-28
- Sensor mast, 12
- Shutdown, 24
- Specifications, 5
- Squareness check, 9
- Startup, 24
- Storage, 26

T
- T-nuts, 8
- Tool attachment, 25
- Troubleshooting, 26

V
- VESC config, 15, 22
- VESC mounting, 14
- Vertical posts, 8

W
- Wiring schematic, 17

Municipal Robotics
Cleveland, Ohio
muni.works

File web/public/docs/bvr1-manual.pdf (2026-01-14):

TECHNICAL MANUAL

# BVR1

Base Vectoring Rover

Revision 1.0 January 2026

Municipal Robotics
Cleveland, Ohio
muni.works

## Contents

BVR1 | Rev 1.0

## About This Manual

This manual is written by the people who built and operate BVR rovers. It’s not a marketing document or a wish list: it’s the real procedures we use, with the mistakes we’ve made and the lessons we’ve learned.

If something is unclear, wrong, or missing, let us know. This is a living document that improves with every build.

Revision History

Rev | Date | Changes
1.0 | January 2026 | Initial release (based on BVR0 manual)

What’s New in BVR1

BVR1 builds on the BVR0 platform with several upgrades:

- Larger wheels: 8″ wheels (vs 6.5″ in BVR0) for better ground clearance and obstacle handling
- Motor brackets: Bicycle-style mounting brackets for easier wheel service and alignment
- Custom battery pack: 13S4P 21700 cells in a dedicated tray (vs downtube battery in BVR0)
- Lighting: Integrated headlights and tail lights for visibility and low-light operation
- Improved sensor mast: Reinforced design with cable routing channels

Most assembly procedures are identical to BVR0. This manual highlights BVR1-specific differences.

Document Conventions

Throughout this manual you’ll see:

“We learned…” | Lessons from real build experience
⚡ COMMON MISTAKE | Errors we’ve seen (and made)
| Difficulty rating (1-3)
15 min | Estimated time for procedure
Municipal Robotics | 4

ℹ NOTE This is a living document. Report errors or suggestions at github.com/muni-works/muni.

# BVR0 Cheat Sheet

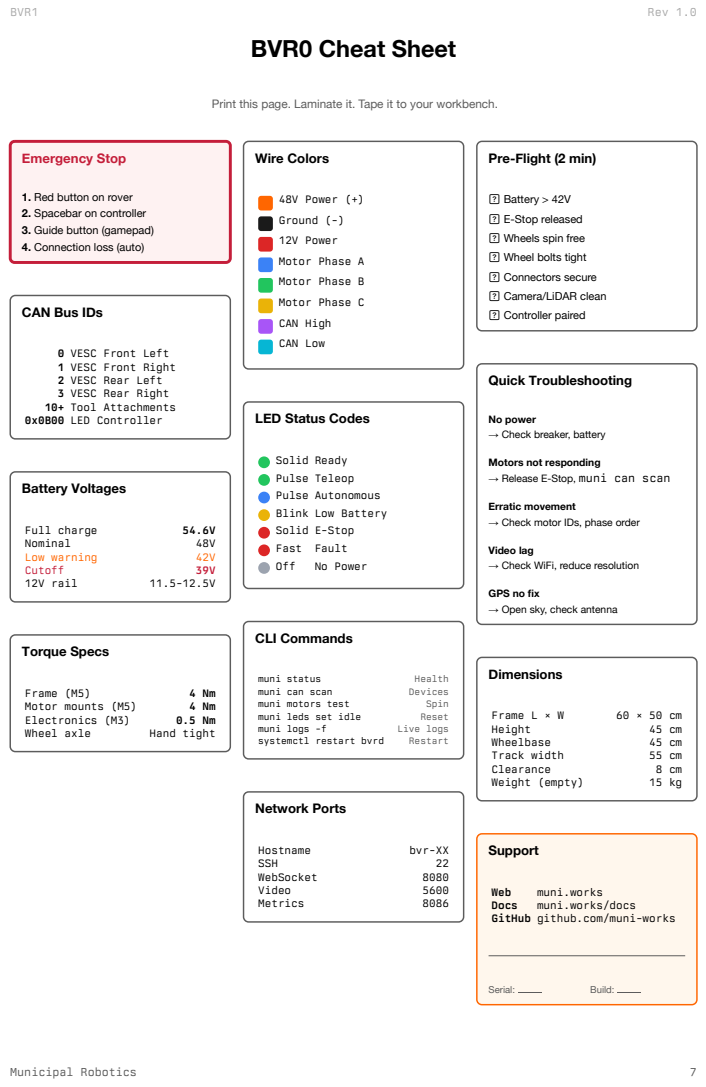
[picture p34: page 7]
Emergency Stop; Battery Voltages; Full charge; Nominal; Low warning; Cutoff; 12V rail; Torque Specs; Frame (M5); Motor mounts (M5); Electronics (M3); Wheel axle; Hand tight; Wire Colors; 48V Power (+); Ground (-); 12V Power; Motor Phase A; Motor Phase B; Motor Phase C; CAN High; CAN Low; Off; No Power; CLI Commands; muni status; Health; muni can scan; Devices; muni motors test; Spin; muni leds set idle; Reset; muni logs -f; Live logs; systemctl restart bvrd; Restart; Network Ports; Hostname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

Print this page. Laminate it. Tape it to your workbench.

Pre-Flight (2 min)

1. Red button on rover
2. Spacebar on controller
3. Guide button (gamepad)
4. Connection loss (auto)

☐ Battery > 42V
☐ E-Stop released
☐ Wheels spin free
☐ Wheel bolts tight
☐ Connectors secure
☐ Camera/LiDAR clean
☐ Controller paired

CAN Bus IDs

0 VESC Front Left
1 VESC Front Right
2 VESC Rear Left
3 VESC Rear Right
10+ Tool Attachments
0x0B00 LED Controller

LED Status Codes

No power
→ Check breaker, battery

Solid Ready
Pulse Teleop
Pulse Autonomous
Blink Low Battery
Solid E-Stop
Fast Fault

Motors not responding
→ Release E-Stop, muni can scan

Erratic movement
→ Check motor IDs, phase order

Video lag
→ Check WiFi, reduce resolution

GPS no fix
→ Open sky, check antenna

GitHub github.com/muni-works

## Quick Reference

These three pages are the ones you’ll use daily. Memorize the e-stop methods. Run the pre-flight checklist every time. Keep the controls layout in your head. Everything else in this manual is for building and fixing. This section is for operating.

## Emergency Stop

⚠ DANGER Know this page. If anything goes wrong, use one of these three methods immediately.

PHYSICAL
BUTTON

Red mushroom
button on rover

1

SPACEBAR

Press spacebar
on controller

2

DISCONNECT

Connection loss
auto-triggers

3

## ALL MOTORS STOP

When to E-Stop:
- Person in path of rover
- Unexpected movement
- Smoke, sparks, or fire
- Loss of control
- Any doubt about safety

To resume after E-Stop:
1. Resolve the cause
2. Release physical button (if used)
3. Reconnect controller
4. Verify telemetry on dashboard
5. Resume operation

## Pre-Flight Checklist

Daily inspection before operation | 2 min

ℹ NOTE If any check fails, do not operate. Resolve the issue first.

“We learned this the hard way:” We once operated with a loose wheel bolt. 10 minutes in, the wheel nearly came off mid-turn. The 2-minute checklist beats a 2-hour field repair.

## Controls

Controller mapping reference | 1 min read
Input | Action
Left Stick Up/Down | Forward / Reverse
Left Stick Left/Right | Turn left / right
Right Stick | Pan camera view
Left Bumper (LB) | Decrease max speed
Right Bumper (RB) | Increase max speed
Left Trigger (LT) | Brake / slow down
Right Trigger (RT) | Throttle (overrides stick)
Guide Button (center) | Emergency Stop
Spacebar (keyboard) | Emergency Stop

## Before You Begin

This section explains what you’re building, what you’ll need, and how long it takes.

What You’re Building

The BVR0 is a four-wheeled skid-steer rover with hub motors, a 48V power system, and onboard compute. It’s designed for outdoor municipal work (snow clearing, mapping, patrol) but the base platform is general-purpose.

Figure 4: Four subsystems: mechanical frame, power distribution, drivetrain, and compute/sensors.

Prerequisites

Skills needed:
- Basic hand tools (hex keys, screwdrivers, wrenches)
- Wire stripping and crimping
- Soldering (through-hole level)
- Comfort with Linux command line
- Ability to read wiring diagrams

You do NOT need:
- CNC or machining (parts are outsourced or hand-cut)
- PCB design (all boards are off-the-shelf)
- Deep embedded programming (firmware is pre-built)

Build Phases

The build has four phases. Complete each before starting the next.

Total: 12-16 hours (split across 2-3 days recommended)

Recommended Order

Day | Tasks | Time
1 | Cut extrusions, assemble frame, mount motor brackets | 4-5 hr
2 | Install motors, wire power system, mount electronics plate | 4-5 hr
3 | Wire VESCs and CAN bus, flash Jetson, configure and test | 4-5 hr

✓ TIP Don’t rush. A clean build with good cable management saves hours of debugging later.

Tools Required

Essential:
- Hex key set (2, 2.5, 3, 4, 5 mm)
- Phillips screwdriver
- Wire strippers (10-22 AWG)
- Crimping tool (for ferrules)
- Soldering iron + solder
- Multimeter
- Heat gun or lighter (heat shrink)

Helpful:
- Torque wrench (4 Nm range)
- Miter saw or hacksaw (for extrusions)
- Deburring tool
- Cable tie gun
- Label maker
- Helping hands (for soldering)

Materials Checklist

Before starting, verify you have:

All BOM items received and inspected

Extrusions cut to length (or stock to cut)

Motor brackets fabricated (or ordered)

Electronics plate fabricated (or ordered)

Battery charged to 50%

Jetson flashed with JetPack

See Appendix A: Bill of Materials for the complete parts list with vendors.

## Overview

The BVR0 is the first rover in the Muni fleet. It’s intentionally simple: a rigid aluminum frame, four hub motors, and enough compute to handle autonomy. No suspension, no steering linkages, no complex mechanisms. Everything that can break has been removed.

The design philosophy is “municipal-grade”: it needs to survive Cleveland winters, sidewalk salt, and the occasional collision with a park bench. The 2020 aluminum extrusion frame can be rebuilt with hardware store parts. The hub motors are the same units used in hoverboards and e-scooters (proven, cheap, replaceable). The electronics are mounted on a single plate that slides out for service.


SIDE VIEW

### 1 Hub motor wheels (×4)

### 2 Electronics bay

### 3 Tool mount

4 360° camera

### 5 LiDAR sensor

### 6 Tool attachment

Dimensions | 600 × 600 × 700 mm
Weight | 30 kg with battery
Speed | 1.0–2.5 m/s
Runtime | 4 hours
Temp range | −20°C to +40°C

## Specifications

These are the target specifications for a standard BVR0 build. Your rover may vary slightly depending on component sourcing and local modifications.

Mechanical

Footprint | 600 × 600 mm
Height | 700 mm (with mast)
Weight | 30 kg
Ground clearance | 50 mm
Wheel diameter | 160 mm
Frame | 2020 aluminum extrusion

Electrical

Main battery | 48V 20Ah (960 Wh)
Chemistry | 13S LiPo
Voltage range | 39–54.6V
Accessory rail | 12V 10A
Main fuse | 100A

Drivetrain

Motors | 4× 350W hub motors
Controllers | 4× VESC 6.7
Drive type | Skid-steer
Max speed | 2.5 m/s
Cruise speed | 1.0 m/s

Perception

LiDAR | Livox Mid-360
Camera | Insta360 X4 (360°)
GPS | RTK-capable (optional)

Compute

Main computer | Jetson Orin NX 16GB
Connectivity | LTE + WiFi
CAN bus | 500K baud

## Required Tools

Hex Keys

2.5, 3, 4, 5 mm

Screwdriver

Phillips 2

Wrenches

8, 10, 13 mm

Multimeter

V / Ω / Continuity

Required
- Hex key set (metric: 2.5, 3, 4, 5 mm)
- Phillips screwdriver (2)
- Adjustable wrench or socket set (8, 10, 13 mm)
- Multimeter (voltage, resistance, continuity)
- Wire strippers (20-12 AWG)
- Soldering iron (40W+) and solder
- Heat shrink assortment
- Miter saw or hacksaw (for extrusions)

Recommended
- Torque wrench (4 Nm for M5)
- Drill and drill bits (3.2, 4.2, 5 mm)
- Tap set (M4×0.7, M5×0.8)
- Deburring tool
- Cable ties (assorted sizes)
- Label maker
- Work mat
- Helping hands / PCB holder

ℹ NOTE All M5 bolts should be torqued to 4 Nm. Over-tightening can strip aluminum threads.

## Parts List

A B

Jetson

C

D

48V 20Ah

E

M5 × 8

F

Parts

A Chassis: extrusions, brackets, plate | $150
B Drivetrain: motors, VESCs | $830
C Electronics: Jetson, CAN, LTE | $900
D Perception: LiDAR, camera, pole | $1,800
E Power: battery, DC-DC, E-stop | $400
F Hardware: bolts, T-nuts, wire | $100

Cost Summary

Chassis | $150
Drivetrain | $830
Electronics | $900
Perception | $1,800
Power | $400
Hardware | $100
Total | $4,180

All parts commercially available.

Full BOM with links:
docs/hardware/bom.md

Where to Buy:

Category | Primary Source
Notes | Extrusions
Amazon, Misumi | 2020 V-slot or T-slot
Motors | AliExpress
Search “hoverboard hub motor 350W” | VESCs
Flipsky | VESC 6.6 or 6.7
Jetson | NVIDIA, Arrow, Seeed
Orin NX 16GB + carrier | LiDAR
Livox / DJI Store | Mid-360, 1 week ship
Camera | Amazon, B&H
Insta360 X4 | Custom cuts
SendCutSend | Upload DXF, 3-5 day turnaround

## Custom Fabricated Parts

BVR0 requires zero custom fabricated parts.

No custom parts needed

How BVR0 avoids custom fabrication:

Component | BVR0 Approach
Alternative (BVR1) | Motor mounting
Direct bolt to 2020 T-slot | Custom brackets
Battery | Downtube e-bike battery
Custom pack + tray | Electronics
Tape/zip-tie to chassis | Custom plate

ℹ NOTE BVR0 is intentionally scrappy. The goal is to get a working rover with parts you can order today and assemble this weekend. No waiting for laser cutting, no CAD required.

Once you’ve proven the concept, BVR1 introduces custom parts for a cleaner, more serviceable build.

## Hardware Reference

Standard fasteners and hardware used throughout the build.

Bolts

Size | Use
M3×8 | Electronics mounting
M5×8 | T-nut, light duty
M5×10 | T-nut, standard
M5×12 | Motor to frame
M5×16 | T-nut, through plate

T-Nuts

Type | Use
M5 drop-in | Post-assembly insertion
M5 slide-in | Pre-assembly (easier)
M6 drop-in | Heavy-duty mounts

Connectors

Type | Rating
Use | XT90
90A | Battery main
XT60 | 60A
Motor phase | XT30
30A | 12V power
JST-PH | 3A
CAN bus, signals | DT 4-pin
25A | Tool connector

Wire Gauge

AWG | Use
8 AWG | Battery to bus
10 AWG | Bus to VESCs
14 AWG | 12V power
22 AWG | CAN bus, signals

Common Hardware (actual size)

M5 × 8

M5×8

M5 × 10

M5×10

M5 × 16
M5×16 | M5 T-Nut | Corner

## Chassis Assembly

The chassis is the skeleton of the rover. It’s built from 2020 aluminum extrusion, the same stuff used in 3D printer frames and CNC machines. The T-slot design means you can mount anything anywhere, and if you mess up a hole, just slide the T-nut to a new position.

The frame goes together like adult LEGO. No welding, no precision machining. If you can use a saw and a hex key, you can build this chassis.

## Cutting Extrusions

Cut aluminum stock to length | 20 min

Cutting Setup

2020 Extrusion

Stop

600

Fence

Procedure:
1. Clamp stop block at 600mm from blade
2. Place extrusion against fence and stop
3. Cut slowly to prevent burrs
4. Rotate 90° and re-cut if needed for square ends
5. Deburr all cut edges with file or deburring tool

Cut List (BVR0 standard):

Qty | Length
Purpose | 4
600mm | Base frame
4 | 600mm
Top frame | 4
250mm | Vertical posts

Total: 5.8m of 2020 extrusion needed.

⚠ WARNING Aluminum chips are sharp. Wear safety glasses. Clean chips from T-slots before assembly.

⚡ COMMON MISTAKE Cutting too fast causes burrs that jam T-nuts. Slow cuts with a fine-tooth blade save deburring time.

## Base Frame Assembly

Assemble the base frame square | 15 min

Assembly Steps:

Diagonals equal?; nut; location

1. Pre-insert T-nuts into all extrusion channels (8 per extrusion, 32 total for base)
2. Dry-fit all four extrusions in a square, corners aligned
3. Attach corner brackets loosely (finger-tight M5×10 bolts)
4. Check squareness: measure both diagonals. They must be equal (±1mm).
5. If not square: tap the long diagonal corner with a mallet to adjust
6. Tighten all bolts to 4 Nm in a star pattern

ℹ NOTE Leave extra T-nuts in channels for later mounting. Easier now than adding drop-in nuts later.

## Vertical Posts

Install corner vertical posts | 10 min

200-400


Mounting Method A: Corner Bracket

Use 90° corner brackets at each post base.

- 2× M5×10 bolts per bracket
- Insert T-nuts in both base and post
- Tighten to 4 Nm

Mounting Method B: Blind Joint

Use blind joint connectors for cleaner look.

- Drill 5mm access hole in base extrusion
- Thread M5×25 bolt through into post
- Hidden hardware, harder to adjust

Height Calculation:

Ground

Wheel

Clearance | 50

Base

250

350 Mast

700

Component | Height
Cumulative | Wheel radius
80mm | 80mm

Ground clearance | 50mm
– | Base to top frame
250mm posts + 40mm | 370mm
Sensor mast | 330mm

700mm

## Top Frame

Complete the box frame | 15 min

Top Frame

Assembly:

1. Attach corner brackets to top of each vertical post (loosely)
2. Place top frame extrusions onto brackets
3. Align extrusions flush with vertical posts
4. Check that top frame is level (use spirit level)
5. Tighten all connections to 4 Nm

ℹ NOTE The top frame provides mounting points for the electronics plate, sensor mast, and protective covers.

## Squareness Check

Verify frame geometry | 5 min
D2 | D1
A | B
D | C

D1 = D2 ± 1mm

Squareness Test:

1. Measure diagonal A→C (D1)
2. Measure diagonal B→D (D2)
3. Compare: D1 should equal D2 within 1mm
4. If not equal: loosen corners, tap long diagonal, re-tighten

Rigidity Test:

1. Grip opposite corners
2. Try to twist the frame
3. Frame should not flex or rack
4. If loose: check all bolt torque, add corner braces if needed

Final Checklist:

All corners have brackets installed; All bolts torqued to 4 Nm; Diagonals equal within 1mm; Frame does not rack or twist; All T-slots clear of debris; Extra T-nuts in channels for later use

✓ TIP Take a photo of the diagonal measurements. Useful reference if the frame gets knocked out of square later.

## Electronics Plate

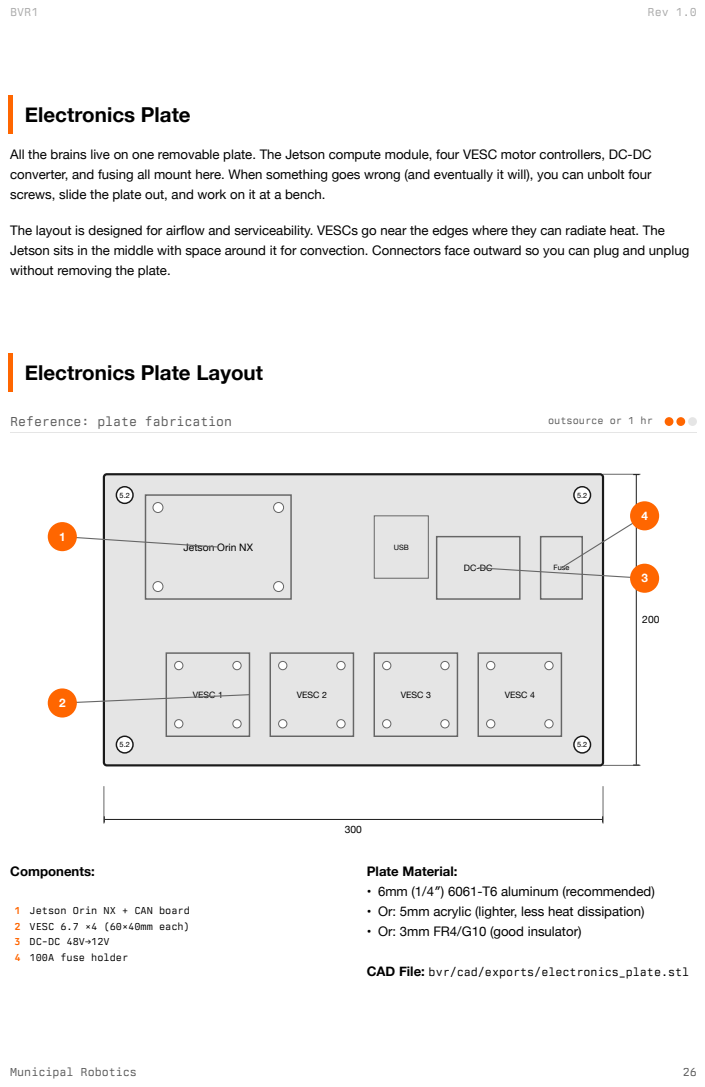
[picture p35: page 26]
Reference: plate fabrication; outsource or 1 hr; VESC 1; VESC 2; VESC 3; VESC 4; Fuse; USB; Components:

All the brains live on one removable plate. The Jetson compute module, four VESC motor controllers, DC-DC
converter, and fusing all mount here. When something goes wrong (and eventually it will), you can unbolt four
screws, slide the plate out, and work on it at a bench.

The layout is designed for airflow and serviceability. VESCs go near the edges where they can radiate heat. The
Jetson sits in the middle with space around it for convection. Connectors face outward so you can plug and unplug
without removing the plate.

Electronics Plate Layout

Jetson Orin NX

Plate Material:
• 6mm (1/4″) 6061-T6 aluminum (recommended)
• Or: 5mm acrylic (lighter, less heat dissipation)
• Or: 3mm FR4/G10 (good insulator)

1 Jetson Orin NX + CAN board
2 VESC 6.7 ×4 (60×40mm each)
4 100A fuse holder

CAD File: bvr/cad/exports/electronics_plate.stl

## Drilling Guide

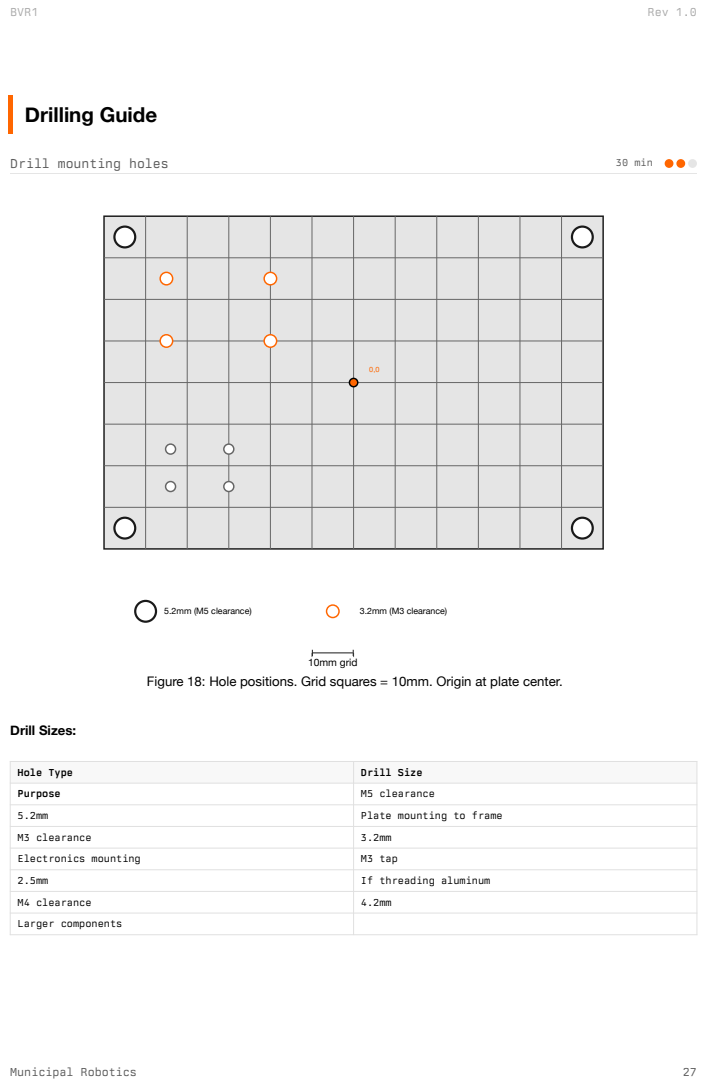
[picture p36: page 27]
Drill mounting holes; 30 min; 5.2mm (M5 clearance); 3.2mm (M3 clearance); 10mm grid; Drill Sizes:

Figure 18: Hole positions. Grid squares = 10mm. Origin at plate center.

Hole Type | Drill Size

Purpose | M5 clearance

5.2mm | Plate mounting to frame

M3 clearance | 3.2mm

Electronics mounting | M3 tap

2.5mm | If threading aluminum

M4 clearance | 4.2mm

Larger components

## Plate Mounting

Mount plate to frame | 15 min

2020 Extrusion

T-Nut

M5×16

Standoff

Electronics Plate

15-25

Figure 19: Cross-section: standoff mounting provides airflow under plate.

Mounting Hardware (per corner):
- 1× M5×16 or M5×20 bolt
- 1× M5 T-nut (drop-in or slide-in)
- 1× M5 standoff (15-25mm height)
- 1× M5 nut or second standoff

Standoff Height:
- 15mm: Minimal, tight fit
- 20mm: Recommended (good airflow)
- 25mm: Maximum cable clearance

Use same height at all 4 corners.

Installation:
1. Insert T-nuts into top extrusion slots
2. Thread M5 bolts through standoffs
3. Position plate on standoffs
4. Align with T-nuts
5. Tighten to 4 Nm

ℹ NOTE Leave plate loose until all electronics are mounted. Easier access.

## Drivetrain

The BVR1 uses skid-steer drive: four independent hub motors, one in each wheel. To turn, the left and right sides spin at different speeds (or opposite directions). It’s the same principle as a tank or a Roomba.

Hub motors eliminate chains, belts, gearboxes, and axles. The motor is the wheel. This means fewer parts, less maintenance, and no drivetrain to align. The tradeoff is that hub motors are heavier than outrunner motors with belt drive, but for a utility rover that’s not a problem.

BVR1 uses 8″ hub motors (larger than BVR0′s 6.5″ hoverboard motors) for improved ground clearance and obstacle handling. These mount via custom brackets rather than directly to the frame, making wheel service easier.

## Motor Bracket Design

Reference: bracket fabrication | outsource or 1 hr

The BVR1 motor brackets use a bicycle-style design: an L-shaped aluminum bracket bolts to the frame, and the motor axle clamps into the bracket’s slot. This allows quick wheel removal without disturbing the frame.

TOP VIEW (1:2 scale)

80

60

42

42

5.2×15 slot

Holes: 4.2mm (M4 clearance)

SIDE VIEW

80

3

50

20

90° bend

Figure 20: Motor bracket dimensions. Material: 3mm 6061-T6 aluminum.

Bracket Specifications:
- Material: 3mm 6061-T6 aluminum
- Overall: 80mm × 60mm flat, 50mm vertical
- Frame slots: 5.2mm × 15mm (M5 adjustment)
- Motor holes: 42mm × 42mm square pattern
- Drill: 4.2mm (M4 clearance)
- Bend: 90° along 80mm edge

CAD Files: Available at bvr/cad/exports/:
- motor_mount_8in.stl (3D model)
- motor_mount_plate_8in.stl
- motor_mount_tab_8in.stl

SendCutSend accepts DXF/STEP files for laser cutting and bending.

ℹ NOTE The 42mm hole pattern fits standard 8″ hub motors. Verify your motor’s bolt pattern before cutting.

## Motor Bracket Mounting

Mount brackets to frame | 15 min

Frame corner

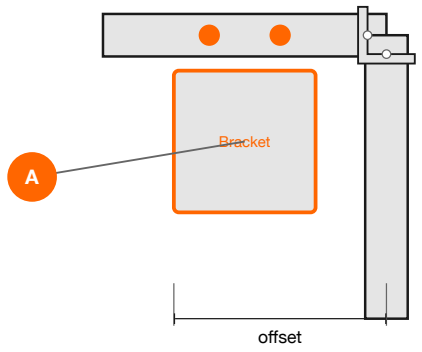
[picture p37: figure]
Bracket; offset

Figure 21: Motor bracket position at frame corner. All 4 corners mirror this layout.

Mounting Procedure:

1. Slide T-nuts into bottom extrusion channel
2. Position bracket with motor axle aligned to wheel position
3. Insert M5×10 bolts through bracket slots into T-nuts
4. Leave bolts finger-tight for adjustment
5. Verify bracket is perpendicular to extrusion
6. Tighten to 4 Nm

Bracket Positions:

Corner | Offset from corner
Front Left | 50mm
Front Right | 50mm
Rear Left | 50mm
Rear Right | 50mm

Alignment Check:
- Motor axles should be parallel
- Equal distance from frame edges
- Perpendicular to travel direction

## Hub Motor Installation

Install hub motors | 30 min

1

2

3

Bracket

M4×8 ×4

Axle | Hub Motor Phase wires
Wheel | Pre-mounted

Figure 22: Motor installation sequence. Wheels typically come pre-mounted on hub motors.

Installation Steps:

1. Align motor mounting holes with bracket holes
2. Insert M4×8 bolts through bracket into motor
3. Tighten in cross pattern to 2 Nm
4. Route phase wires toward electronics bay
5. Secure wires with cable ties (leave slack for wheel movement)

⚠ WARNING Do not pinch phase wires between motor and bracket. This can cause shorts.

“We learned this the hard way:” The first motor install was tight. Really tight. We cross-threaded an M4 bolt and stripped the motor housing. Now we hand-thread every bolt first before using a driver.

## Wheel Alignment

Check and adjust wheel alignment | 15 min
d1 | d2
d1 = d2 ± 2mm at front and rear
Figure 23: String alignment method. Stretch strings parallel to frame sides.

Alignment Procedure:

1. Stretch two parallel strings along frame sides
2. Measure gap from string to front wheel edge
3. Measure gap from string to rear wheel edge
4. Gaps should be equal (±2mm) on each side
5. If not equal: loosen bracket, adjust, re-tighten

Common Issues:

Symptom | Cause
Fix | Rover pulls left
Right wheels toe-in | Adjust right brackets outward
Rover pulls right | Left wheels toe-in
Adjust left brackets outward | Excessive tire wear
Wheels not parallel | Realign all brackets
Vibration at speed | Wheel out of round

Replace tire or motor

## Power System

The rover runs on 48V nominal (13S lithium). This voltage is high enough to be efficient (less current means thinner wires and less heat) but low enough to avoid the regulatory complexity of “high voltage” systems.

BVR1 uses a custom battery pack instead of an off-the-shelf downtube battery. This allows for a form factor optimized for the rover’s layout and higher capacity cells.

The power path is simple: battery → fuse → e-stop relay → distribution bus → loads. Every component can be isolated, and the e-stop cuts power to everything downstream instantly.

Respect the battery. A 48V 20Ah pack stores nearly 1 kWh of energy. That’s enough to weld metal if shorted, or start a fire if punctured. The safety section covers handling in detail.

## Battery Pack

Install custom battery pack | 20 min

BVR1 uses a custom 13S4P battery pack built with 21700 cells. The pack mounts in a dedicated tray with integrated BMS and Anderson PowerPole connectors.

Frame rail

Tray

48V 28Ah

13S4P 21700

Retention strap

Anderson

200mm
Figure 24: Custom battery pack mounted in tray with retention strap.

Pack Specifications:
- Configuration: 13S4P (48V nominal)
- Cells: Samsung 50E or Molicel P42A
- Capacity: 28Ah (1,344 Wh)
- Max discharge: 80A continuous
- BMS: 13S 100A with balancing
- Connector: Anderson SB50 or similar

Tray Construction:
- Material: 2mm 6061-T6 aluminum
- Flat size: 240mm × 180mm
- Bend: 15mm lip on all 4 sides (90°)
- 10mm EVA foam padding (bottom)
- Retention: 25mm nylon strap + cam buckle

CAD File: bvr/cad/battery-tray.dxf

⚠ WARNING Battery must not shift during operation. Loose batteries can short on frame, causing fire.

## Fuse and E-Stop

Wire safety disconnect | 30 min

BVR1 adds proper safety systems that BVR0 lacks. The design philosophy: one main fuse protects the wiring, one relay provides software-controlled shutdown.

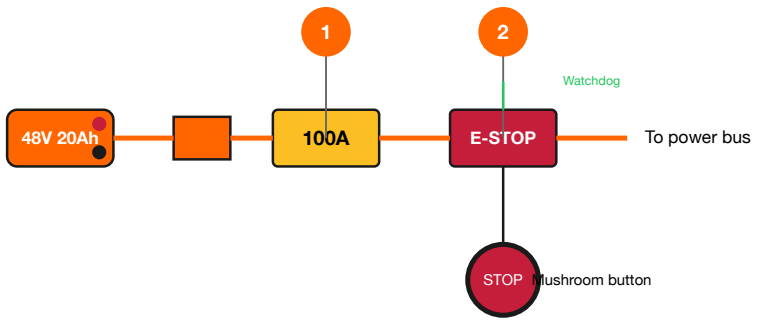
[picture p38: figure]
E-STOP; To power bus; STOP Mushroom button; Watchdog

Figure 25: Power flows: Battery → Connector → Fuse → E-Stop relay → Power bus

### 1 Main Fuse (100A):

- ANL or MIDI style fuse
- Inline fuse holder with ring terminals
- Protects main wiring from shorts
- Mount accessible for replacement
- Sized for wire gauge, not load

### 2 E-Stop Relay:

- Normally-open contactor
- 12V coil with watchdog timer
- 100A+ contact rating
- Fails safe: power loss = motors stop
- Physical button + software control

Why no per-VESC fuses? VESCs have built-in overcurrent protection. Adding fuses per VESC would only protect the short wire run from bus to VESC. The main fuse protects the longer battery-to-bus wiring where a short is most likely.

## E-Stop Relay Wiring

Wire GPIO to relay | 15 min

The e-stop relay is controlled by the Jetson’s GPIO. A normally-open relay means the default state (GPIO LOW at boot) keeps motors disabled.

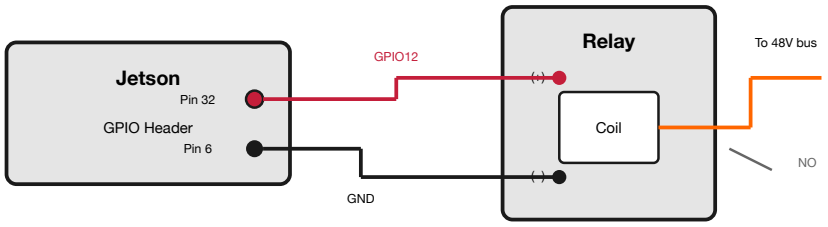
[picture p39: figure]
Jetson; GPIO Header; Pin 32; Pin 6; Relay; Coil; GPIO12; GND; To 48V bus

Figure 26: E-stop relay wiring. GPIO12 HIGH closes relay, enabling motor power.

Wiring:
- Jetson Pin 32 (GPIO12) → Relay coil (+)
- Jetson Pin 6 (GND) → Relay coil (−)
- Relay contacts in series with 48V bus

Relay Selection:
- Coil: 3.3V or 5V (with transistor driver)
- Contacts: 100A+ DC rated
- Type: Normally-Open (NO)
- Example: TE Connectivity EV200

Operation:
- Boot: GPIO12 is LOW → relay open → motors disabled
- Software sets GPIO12 HIGH → relay closes → motors enabled
- Watchdog timeout → GPIO12 goes LOW → motors disabled
- Physical e-stop button breaks coil circuit → motors disabled

“We learned this the hard way:” The first prototype used a normally-closed relay. A boot glitch meant motors got power before software loaded. Now we always use normally-open for fail-safe.

## Lighting System

Install headlights and tail lights | 30 min

BVR1 includes integrated lighting for visibility and safety. Headlights illuminate the path ahead for camera perception in low light. Tail lights provide visibility to pedestrians and vehicles.

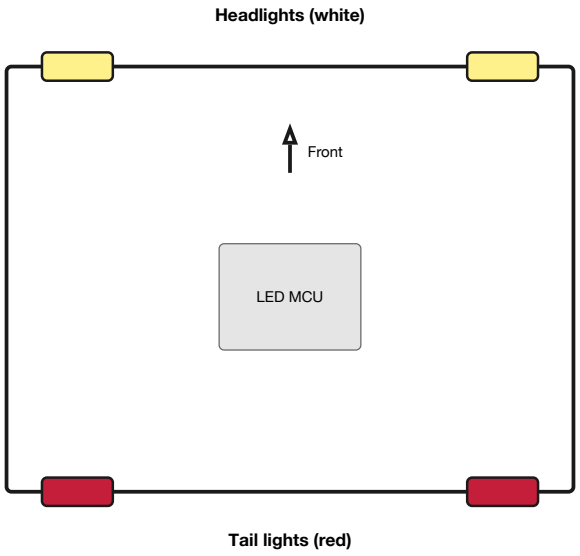
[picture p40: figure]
Headlights (white); Tail lights (red); Front; LED MCU

Figure 27: Light positions: white headlights front, red tail lights rear.

Headlights:
- 2× high-power white LED modules
- 12V, 5W each
- Wide beam for path illumination
- Mount to front frame rail
- Controlled via CAN bus from MCU

Tail Lights:
- 2× red LED strips or modules
- 12V, 2W each
- Always on when rover is powered
- Mount to rear frame rail
- Can flash during reversing

Wiring:
- Lights connect to LED MCU (RP2350)
- MCU receives commands over CAN bus
- 12V power from DC-DC converter
- Use 18 AWG wire for light circuits

Light States:

State | Headlights
Tail Lights | Idle
Off | Dim (10%)

Teleop | On
On | Autonomous
On | On
Reversing | On
Flashing | E-Stop
Off | Fast flash

## DC-DC Converter

Install voltage regulator | 10 min

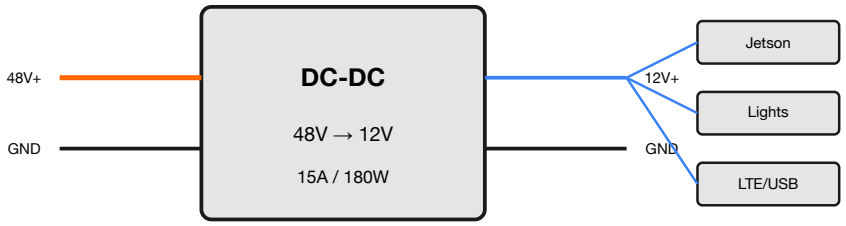
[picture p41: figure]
GND; Jetson; Lights; LTE/USB

Figure 28: DC-DC powers all 12V devices including lighting.

Specifications:

Parameter | Value
Input voltage | 36-60V (fits 13S LiPo range)
Output voltage | 12V regulated
Output current | 15A continuous
Efficiency | >90%
Mounting | M3 holes, heatsink on bottom

12V Load Budget:

Device | Current
Jetson Orin NX | 5A peak, 3A average
Headlights | 1A
Tail lights | 0.5A
LTE modem | 1A
USB hub | 0.5A
Accessories | 1A reserve
Total | 8A typical, 12A max

ℹ NOTE BVR1 uses a 15A DC-DC (vs 10A in BVR0) to handle the additional lighting load.

## Power Distribution

Wire power bus | 45 min

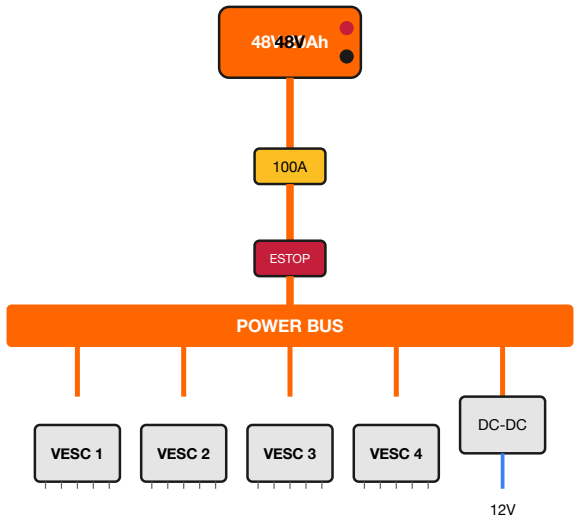
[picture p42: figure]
ESTOP; POWER BUS; VESC 1; VESC 2; VESC 3; VESC 4

Figure 29: Power distribution topology. All 48V loads connect to central bus.

Bus Options:

Bus Bar (recommended):
- Solid copper bar with tapped holes
- Clean, low resistance
- Easy inspection

Splitter Cable:
- Anderson to 4× XT60
- Simpler for prototypes
- Higher resistance

## Electronics

The electronics are the nervous system: motor controllers that translate commands into wheel motion, a compute module that runs the autonomy stack, and a CAN bus that ties everything together.

We use VESC motor controllers because they’re open-source, powerful, and have a decade of real-world use in electric skateboards and robotics. The Jetson Orin NX handles perception and planning. It’s overkill for teleoperation, but essential for autonomous operation.

## VESC Mounting

Mount motor controllers | 20 min

VESC 6.7

60V 100A

Heatsink (face up)

48V+

GND

Phase A

Phase B

Phase C

CAN

M3 standoffs (6-10mm)
Figure 30: VESC mounted on standoffs for airflow. Heatsink faces up.

Mounting:
- M3×6 standoffs at all 4 corners
- M3×8 bolts through plate into standoffs
- Thermal pad between VESC and plate (optional, for heat transfer)

Power Connections:
- 10 AWG wire for 48V input
- XT60 connectors recommended
- Keep power wires short

⚡ COMMON MISTAKE VESCs generate serious heat under load. Without standoffs for airflow, thermal throttling kicks in after 3 minutes of hard driving.

## VESC Configuration

Set CAN IDs and motor parameters | 10 min per VESC

FRONT

Figure 31: CAN ID assignment. ID 0-3 for wheels, ID 10+ for tools.

VESC Tool Configuration:

Parameter | Value
Controller ID | 0, 1, 2, 3 (unique per VESC)
CAN Mode | VESC
CAN Baud Rate | CAN_500K
Send CAN Status | Enabled
CAN Status Rate | 50 Hz
Motor Type | BLDC or FOC (depends on motor)
Current Limit | 30A (per motor)

Motor Detection:

1. Connect VESC to computer via USB
2. Open VESC Tool
3. Run Motor Detection wizard
4. Save configuration to VESC
5. Disconnect USB, connect CAN

## Jetson Mounting

Install compute module | 15 min

Jetson Orin NX; Carrier Board; USB 3.0; USB-C; Ethernet; Airflow

Figure 32: Jetson mounted on standoffs. Ensure airflow around heatsink.

Connections:

Port | Connection
CAN pins | CAN transceiver module
USB 3.0 | USB hub (camera, LTE)
12V DC | From DC-DC converter
GPIO | Not used (e-stop is hardwired)

Software:
- JetPack 6.0 or later
- bvrd daemon (auto-start on boot)
- Insta360 SDK for camera

Jetson Setup:

# Flash JetPack 6.0 using SDK Manager on host PC # After boot, install dependencies:

sudo apt update && sudo apt install -y can-utils pip install pyserial

# Clone firmware repo

git clone https: /github.com/muni-works/muni cd muni/bvr/firmware

# Build and install bvrd

cargo build -release
sudo cp target/release/bvrd /usr/local/bin/

sudo cp config/bvrd.service /etc/systemd/system/ sudo systemctl enable bvrd

Full setup instructions at github.com/muni-works/muni. (https://github.com/muni-works/muni/blob/main/bvr/firmware/README.md)

## GPIO Pinout

Reference: GPIO connections | 5 min

BVR0 uses minimal GPIO: just the CAN interface on the carrier board. The E-stop is wired directly in the power path (not relay-controlled). BVR1 adds GPIO-controlled e-stop relay and watchdog.

40-Pin Header (pins 1-20)

1 | 2
3 | 4
5 | 6
7 | 8
9 | 10
11 | 12
13 | 14
15 | 16
17 | 18
19 | 20

3.3V

GND

5V

BVR0: No GPIO used. CAN via carrier board.
Figure 33: GPIO header reference. BVR0 uses carrier board CAN, not GPIO.

BVR0 GPIO Usage:

BVR0 doesn’t use any GPIO pins directly. The CAN bus is provided by the carrier board’s dedicated CAN controller (not bit-banged GPIO).

Pin | Function
BVR0 | BVR1
1 | 3.3V
Unused | Status LED
2 | 5V
Unused | Unused
6 | GND
Unused | E-Stop ground
32 | GPIO12
Unused | E-Stop relay

ℹ NOTE BVR1 adds e-stop relay on GPIO12. See BVR1 manual for wiring details. The relay is normally-open: GPIO LOW = motors disabled (fail-safe).

## CAN Transceiver

Connect CAN bus interface | 10 min

The Jetson carrier board (Seeed reComputer J401 or similar) has CAN controller pins exposed. A CAN transceiver module converts these logic-level signals to the differential CAN bus.

Jetson Carrier; reComputer J401; CAN_TX; CAN_RX; CAN; Transceiver; CAN_H; CAN_L; GND; Onboard term.

Figure 34: CAN transceiver connects carrier board CAN pins to differential bus.

Transceiver Modules:
- Waveshare SN65HVD230 module
- Any 3.3V CAN transceiver breakout
- Often included on carrier board (check your model)

Wiring:

Carrier Pin | Transceiver
Notes | CAN_TX
TXD | Logic level out
CAN_RX | RXD
Logic level in | 3.3V
VCC | Power
GND | GND

Common ground

Configuration:

# Enable CAN interface (may vary by carrier board) sudo modprobe mttcan

sudo ip link set can0 type can bitrate 500000 sudo ip link set can0 up

# Test with candump

candump can0

Termination:
- Most transceiver modules have onboard 120Ω termination
- CAN bus needs exactly 2 termination resistors (one at each end)
- If transceiver is at bus end: enable termination
- Verify: measure 60Ω across CAN_H/CAN_L (two 120Ω in parallel)

⚡ COMMON MISTAKE The reComputer carrier uses the Jetson’s native CAN controller (mttcan driver), not a USB adapter. Check your carrier’s pinout for CAN_TX/CAN_RX locations.

## Sensor Mast

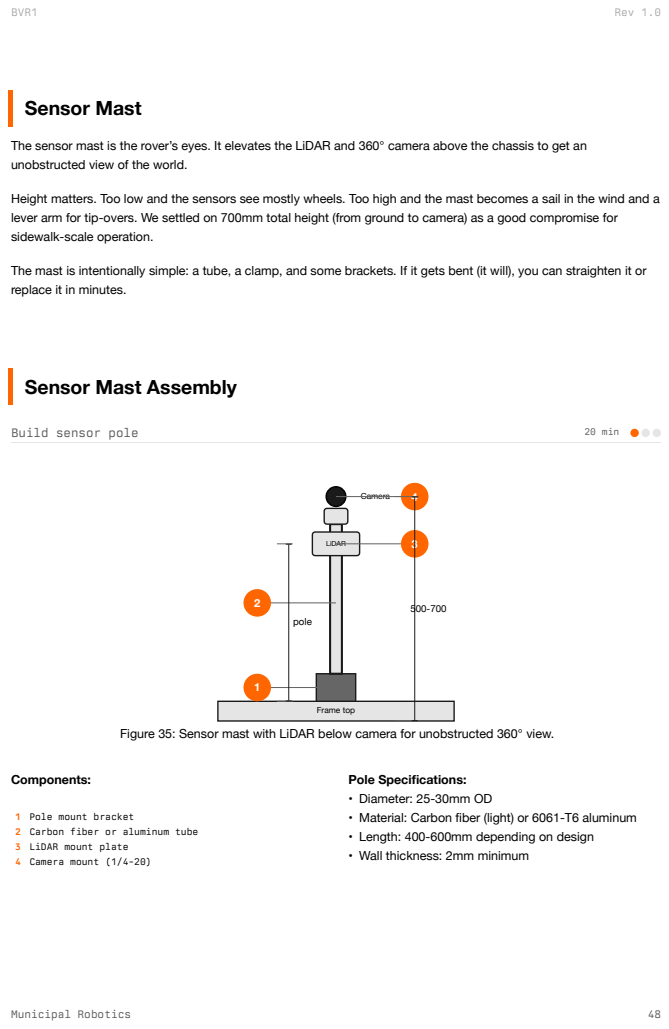
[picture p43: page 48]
Build sensor pole; 20 min; Frame top; LiDAR; Camera; pole; Components:

The sensor mast is the rover’s eyes. It elevates the LiDAR and 360° camera above the chassis to get an
unobstructed view of the world.

Height matters. Too low and the sensors see mostly wheels. Too high and the mast becomes a sail in the wind and a
lever arm for tip-overs. We settled on 700mm total height (from ground to camera) as a good compromise for
sidewalk-scale operation.

The mast is intentionally simple: a tube, a clamp, and some brackets. If it gets bent (it will), you can straighten it or
replace it in minutes.

Sensor Mast Assembly

Figure 35: Sensor mast with LiDAR below camera for unobstructed 360° view.

Pole Specifications:
• Diameter: 25-30mm OD
• Material: Carbon fiber (light) or 6061-T6 aluminum
• Length: 400-600mm depending on design
• Wall thickness: 2mm minimum

1 Pole mount bracket
2 Carbon fiber or aluminum tube
3 LiDAR mount plate
4 Camera mount (1/4-20)

## LiDAR Mounting

Mount LiDAR sensor | 15 min

Figure 36: Top view: full 360° sensing

SIDE VIEW

Mid-360 | Cable

Bracket

Pole
Figure 37: Side view: cable routes down

Installation:

1. Attach LiDAR to mount plate with M3 bolts
2. Level the mount plate (use spirit level)
3. Secure mount plate to pole with hose clamps or bolts
4. Route cable inside pole or along outside with ties
5. Connect to Jetson via Ethernet

Orientation:
- LiDAR “front” should face rover front
- Ensure level within ±1°
- No obstructions in 360° view

## Camera Mounting

Mount 360° camera | 10 min

X4

Lens (front)

Lens (rear)

1/4-20 mount

Adapter

360° × 180°

Figure 38: Camera at mast top. Dual lenses capture full spherical view.

Mount Options:
- 1/4-20 threaded insert in pole top cap
- GoPro-style mount adapter
- Custom 3D-printed adapter

Cable Routing:
- USB-C cable to Jetson
- Route inside pole if possible
- Secure with cable ties
- Leave strain relief loop at camera

Camera Settings:

Setting | Value
Mode | Live streaming (H.265)
Resolution | 4K or 5.7K
Frame rate | 30 fps
Stabilization | FlowState (on)

## Wiring

Wiring is where builds go wrong. A loose connection causes intermittent failures. A reversed polarity destroys components. A pinched wire works fine until it doesn’t.

Take your time here. Label every wire. Double-check polarity before applying power. Use the correct gauge wire for the current it carries. The extra hour spent on clean wiring saves days of debugging later.

The schematic on the next page shows the complete system. Study it before you start, and refer back to it often.

## System Wiring Schematic

Reference: complete wiring diagram | reference

POWER

COMPUTE

Legend

48V Power

12V Power

CAN Bus

Signal/USB
Figure 39: Complete system wiring. Power flows left, compute/sensors right.

## CAN Bus Wiring

Wire CAN bus network | 30 min

Jetson; Tool; CAN_H (black); CAN_L (gray)

Figure 40: CAN bus with 120Ω termination at each end (A and B).

Wiring Rules:

- Use twisted pair wire (22 AWG)
- CAN_H to CAN_H, CAN_L to CAN_L at each device
- Maximum total bus length: 40m at 500K baud
- Exactly 2 termination resistors (one at each end)
- Keep CAN wires away from motor phase wires

JST Connector Pinout:

Pin | Signal
Color (typical) | 1
GND | Black
2 | CAN_L
Gray or White | 3
CAN_H | Orange or Yellow
4 | +5V (optional)

Red
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

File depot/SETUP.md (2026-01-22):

# Depot Setup Guide

Step-by-step instructions for deploying a new depot (base station).

## Prerequisites

- [ ] Server hardware assembled (see [docs/hardware/depot.md](../docs/hardware/depot.md))
- [ ] Linux installed (Raspberry Pi OS, Ubuntu, or similar)
- [ ] Docker and Docker Compose installed
- [ ] Network connectivity (Ethernet to router/switch)
- [ ] RTK antenna mounted with clear sky view (if using RTK)

## Quick Start (5 minutes)

For a quick development setup:

```bash
cd depot
docker compose up -d
```

This starts all services with default (insecure) credentials. For production, follow the full setup below.

---

## Full Setup Checklist

### 1. Clone Repository

```bash
git clone https://github.com/muni-ai/muni.git
cd muni/depot
```

### 2. Generate Credentials

Run the provisioning script to generate unique, secure credentials:

```bash
./scripts/provision.sh
```

This creates a `.env` file with:

- Console password (for web UI access)
- InfluxDB admin password and API token
- Grafana admin password
- NTRIP password (for RTK corrections)

**Review the generated `.env`:**

```bash
cat .env
```
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

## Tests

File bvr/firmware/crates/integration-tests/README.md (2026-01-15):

# Autonomy Stack Integration Tests

This directory contains integration tests for the BVR firmware autonomy stack.

## Overview

While unit tests live alongside the code in each crate (`#[cfg(test)]` modules), integration tests here validate the full pipeline from odometry through localization to planning and control.

**Test Categories:**
1. **Odometry Tests** - Differential drive kinematics, arc motion, covariance propagation
2. **Localization Tests** - Coordinate frames, EKF sensor fusion, scan matching
3. **SLAM Tests** - Loop closure detection, pose graph optimization, map building
4. **Planning Tests** - Path planning, obstacle avoidance, trajectory generation
5. **Full Pipeline Tests** - End-to-end autonomy loop with simulated environment

## Running Tests

### All integration tests
```bash
cd bvr/firmware
cargo test --tests
```

### Specific test file
```bash
cargo test --test autonomy_integration
```

### Specific test function
```bash
cargo test --test autonomy_integration test_odometry_straight_line
```

### Include ignored tests (slow or incomplete)
```bash
cargo test --tests -- --ignored
```

### Run with logging
```bash
RUST_LOG=debug cargo test --tests -- --nocapture
```

## Test Structure

```
tests/
├── README.md                    # This file
├── autonomy_integration.rs      # Main integration tests
├── slam_scenarios.rs            # SLAM-specific tests (TODO)
├── planning_scenarios.rs        # Path planning tests (TODO)
└── common/
    ├── mod.rs                   # Shared test utilities
    ├── synthetic_scans.rs       # LiDAR scan generators (TODO)
    └── test_environments.rs     # Simulated worlds (TODO)
```

## Test Utilities (common/)

The `common/` module provides reusable utilities for tests:

### Synthetic LiDAR Scans
```rust
use common::generate_box_room_scan;

let scan = generate_box_room_scan(10.0, 10.0, 360);
// Returns 360 (range, angle) pairs for a 10m x 10m room
```

### Differential Drive Simulation
```rust
use common::simulate_differential_drive;

let new_pose = simulate_differential_drive(
    current_pose,
    left_vel,
    right_vel,
    wheel_radius,
    track_width,
    dt,
);
```

### Pose Assertions
```rust
use assert_pose_approx_eq;

assert_pose_approx_eq!(actual_pose, expected_pose, 0.01);
// Asserts poses are within 1cm and 0.01 radians
```

## Writing New Tests

### Integration Test Template
```rust
#[test]
fn test_my_feature() {
    // 1. Setup (create environment, initial state)
    let initial_pose = Isometry2::identity();

    // 2. Execute (run the algorithm/pipeline)
    let result = my_algorithm(initial_pose);

    // 3. Verify (check correctness)
    assert!(result.is_ok());
    assert_pose_approx_eq!(result.unwrap(), expected_pose, 0.01);
}
```

### Property-Based Test Template
```rust
#[test]
fn test_invariant_holds() {
    for _ in 0..1000 {
        let random_input = generate_random_input();
        let result = my_algorithm(random_input);

        // Check invariant (e.g., covariance stays positive definite)
        assert!(check_invariant(result));
    }
}
```

### Simulation Test Template
```rust
#[test]
fn test_scenario() {
    let mut state = initial_state();

    // Simulate multiple timesteps
    for t in 0..1000 {
        let sensor_data = simulate_sensors(&state);
        state = update_state(state, sensor_data);

        // Check invariants at each step
        assert!(state.is_valid());
    }

    // Check final result
    assert_eq!(state.position, expected_position);
}
```

## Test Dependencies

Integration tests have access to all workspace crates plus:
- `nalgebra` - Matrix math, SE(2) transforms
- `rand` - Random number generation for property tests
- `approx` - Floating-point comparisons (TODO: add to Cargo.toml)

Add test-specific dependencies to the workspace `Cargo.toml`:
```toml
[dev-dependencies]
approx = "0.5"
proptest = "1.0"  # For property-based testing
```

## Testing Strategy

### Week 1: Foundation
- [x] Odometry tests (straight line, arc motion)
- [x] Coordinate frame tests
- [x] Covariance propagation tests
- [ ] LiDAR driver tests (with mock data)

### Week 2: SLAM
- [ ] Scan matching tests (correlative scan matcher)
- [ ] EKF tests (predict/update cycle)
- [ ] Pose graph tests (loop closure detection)
- [ ] Occupancy grid tests (ray tracing, log-odds)

### Week 3: Planning
- [ ] Costmap tests (layering, inflation)
- [ ] Global planner tests (Hybrid A*)
- [ ] Local planner tests (DWA)
- [ ] Trajectory tracking tests

### Week 4: Integration
- [ ] Full autonomy pipeline (odometry → localization → planning → control)
- [ ] 10+ consecutive runs without crashes
- [ ] Performance benchmarks (100Hz state estimation, 10Hz planning)

## Performance Testing

Track these metrics during Week 4:

```bash
# Run with timing instrumentation
cargo test --release --tests -- --nocapture | grep -E "time|ms"

# Profile a specific test
cargo flamegraph --test autonomy_integration -- test_full_autonomy_pipeline
```

**Target Performance:**
- Odometry update: <1ms (100Hz capable)
- EKF update: <1ms (100Hz capable)
- Scan matching: <100ms (10Hz capable)
- Path planning: <500ms (acceptable for goal changes)

## Continuous Integration

These tests should run on every commit during the Artifact program:

```yaml
# .github/workflows/autonomy-tests.yml
name: Autonomy Tests
on: [push, pull_request]

jobs:
  test:
    runs-on: ubuntu-latest
    steps:
      - uses: actions/checkout@v4
      - uses: dtolnay/rust-toolchain@stable
      - run: cargo test --tests
```

## Visual Debugging with Rerun

For complex scenarios, generate Rerun recordings:

```rust
#[test]
fn test_with_recording() {
    use rerun as rr;

    let rec = rr::RecordingStreamBuilder::new("test")
        .save("test_output.rrd")
        .unwrap();

    // Log test data
    rec.log("world/robot/pose", &rr::Transform3D::from_translation([x, y, 0.0])).unwrap();

    // Run test
    let result = my_algorithm();

    // View with: rerun test_output.rrd
}
```

## Troubleshooting

### Tests fail with "matrix not invertible"
- Check that covariances are positive definite
- Add regularization: `matrix + Matrix3::identity() * 1e-6`
- Use `try_inverse()` instead of `inverse()`

### Tests fail with angle wrapping issues
- Ensure all angles normalized to [-π, π]
- Use `normalize_angle()` after arithmetic

### Tests are slow
- Use `--release` for performance testing: `cargo test --release --tests`
- Profile with `cargo flamegraph`
- Consider using `#[ignore]` for slow tests

### Flaky tests (pass/fail randomly)
- Likely numerical precision issue
- Increase tolerances or use more iterations
- Check for race conditions in async code

## References

- [artifact-plan.md](../../../docs/artifact-plan.md) - Implementation specifications
- [CLAUDE.md](../../../CLAUDE.md) - Codebase overview
- [Rust testing guide](https://doc.rust-lang.org/book/ch11-00-testing.html)

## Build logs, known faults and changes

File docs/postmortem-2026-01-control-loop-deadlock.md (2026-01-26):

# Postmortem: Control Loop Deadlock During LiDAR Streaming

**Date**: January 23-24, 2026
**Duration**: ~8 hours of debugging
**Severity**: Critical (motor control loop completely frozen)
**Status**: Resolved

## Executive Summary

The bvrd control loop would hang indefinitely approximately 10-16 seconds after a WebRTC client connected with LiDAR streaming enabled. The root cause was calling `recorder.log_lidar_scan()` (which uses the rerun SDK internally) while holding a `std::sync::Mutex`. The rerun SDK uses rayon for parallel processing, and this interaction caused a deadlock that froze the 100 Hz motor control loop.

## Timeline

### January 23, 2026

**~14:00** - Initial report: Control loop hangs after WebRTC connection with LiDAR streaming enabled. Loop runs fine without LiDAR, or with LiDAR but no WebRTC connection.

**~14:30** - First hypothesis: tokio runtime starvation. The control loop was using `tokio::time::sleep().await` which depends on the tokio scheduler. WebRTC tasks might be starving the control loop.

**~15:00** - Attempted fix #1: Replaced `tokio::sync::Mutex` with `std::sync::Mutex` for the shared state. Rationale: tokio mutexes can cause issues when held across await points.

**Result**: No improvement. Loop still hangs.

**~15:30** - Attempted fix #2: Replaced `tokio::time::sleep().await` with `std::thread::sleep()` in the control loop. Rationale: Remove dependency on tokio scheduler for timing.

**Result**: No improvement. Loop still hangs.

**~16:00** - Attempted fix #3: Moved entire control loop to a dedicated `std::thread::spawn()` instead of running in tokio task. Rationale: Complete isolation from async runtime.

**Result**: No improvement. Loop still hangs at exactly the same point (~iteration 1600).

**~16:30** - Added heartbeat monitoring thread to detect hangs. Separate thread prints "STUCK" if iteration counter doesn't advance for 5 seconds.

**Result**: Confirmed loop is genuinely stuck, not just slow. Heartbeat shows iteration frozen at 1615.

**~17:00** - Added PHASE checkpoint logging throughout control loop to identify exact hang location:
- PHASE 0a: after sleep
- PHASE 0b: CAN recv done
- PHASE 1: CAN process done
- PHASE 2: estop done
- PHASE 3: dispatch done
- PHASE 4: nav done
- PHASE 5: motor done
- PHASE 5a-5r: granular telemetry/recording phases
- PHASE 6: telemetry done

**~17:30** - First checkpoint deployment. Logs showed loop progressing through all phases normally until hang.

**Problem**: journald rate limiting suppressed 3909+ messages, hiding the exact hang point.

**~18:00** - Reduced checkpoint frequency (every 10th iteration) and added verbose mode after iteration 900. Still couldn't pinpoint exact location due to log suppression.

**~18:30** - Pivoted to GDB debugging. Attached to running process during hang:
```bash
ssh frog-0 "sudo gdb -p $(pgrep bvrd) -batch -ex 'thread apply all bt'"
```

**Key finding**: Thread 17 (control loop) blocked on `std::sys::sync::mutex::futex::Mutex::lock_contended()`. This was the smoking gun - the loop was blocked trying to acquire a mutex.

**~19:00** - Analyzed thread dump:
- Thread 17 (control loop): blocked on mutex
- Threads 10-13: rayon worker threads (from rerun SDK)
- Thread 1: tokio runtime

The presence of rayon threads was suspicious - we don't use rayon directly.

### January 24, 2026

**~03:30** - Root cause identified: `recorder.log_lidar_scan()` was being called while holding the `shared` mutex (line 2081). The rerun SDK internally uses rayon for parallel processing. When rayon workers interact with the mutex in certain ways, it causes a deadlock.

**~03:45** - Fix implemented: Removed `recorder.log_lidar_scan()` from the critical section. LiDAR data is now:
1. Cloned outside the mutex lock
2. Sent to SLAM background task (non-blocking)
3. Used for costmap updates only

Recording of LiDAR scans disabled for now (TODO: move to async recording task).

**~04:00** - Fix deployed and verified. Control loop ran continuously past iteration 11,000+ with LiDAR streaming enabled. Previously hung at ~1,600.

**~04:05** - Cleanup: Removed all PHASE debug checkpoints from main.rs. Kept heartbeat monitoring thread for future debugging.

## Root Cause Analysis

### The Bug

```rust
// BEFORE (problematic):
let mut state = shared.lock().unwrap();  // Acquire mutex
// ... motor commands, telemetry building ...

if let Some(ref scan) = &*lidar_rx.borrow_and_update() {
    let _ = recorder.log_lidar_scan(scan);  // <-- DEADLOCK HERE
    // rerun SDK uses rayon internally
    // rayon workers somehow interact with mutex
}
```

### Why It Deadlocked

1. Control loop acquires `shared` mutex
2. Control loop calls `recorder.log_lidar_scan()`
3. Rerun SDK spawns work on rayon thread pool
4. Rayon workers (or rerun internals) attempt to acquire same mutex or block in a way that prevents the control loop from releasing it
5. Control loop cannot proceed, mutex never released
6. Deadlock

This is a **known rayon limitation** documented in [rayon-rs/rayon#592](https://github.com/rayon-rs/rayon/issues/592): "Using rayon under a Mutex can lead to deadlocks". Rayon's work-stealing behavior can cause implicit lock recursion when a mutex is held while calling into rayon-using code.

**The rule**: Never call into libraries that use rayon (or any work-stealing thread pool) while holding a mutex.

### Why It Only Happened With LiDAR + WebRTC

- Without LiDAR: `log_lidar_scan()` never called
- Without WebRTC: Different code path, possibly different timing that avoided the race
- With both: Increased load on rerun SDK triggered the deadlock

## The Fix

```rust
// AFTER (fixed):
// Clone scan OUTSIDE the mutex lock
let lidar_scan_clone = if lidar_rx.has_changed().unwrap_or(false) {
    lidar_rx.borrow_and_update().clone()
} else {
    None
};

// Process LiDAR without holding shared mutex
if let Some(ref scan) = lidar_scan_clone {
    // Send to SLAM (non-blocking channel)
    if let Some(ref tx) = slam_scan_tx {
        let _ = tx.try_send((scan.clone(), pose_estimator.pose()));
    }

    // Update costmap (doesn't use rerun)
    if let Some(ref mut nav) = navigation_controller {
        nav.update_costmap(&scan, &robot_tf);
    }

    // NOTE: recorder.log_lidar_scan() removed - was causing deadlock
    // TODO: Move to async recording task
}
```

## What We Tried (And Why It Didn't Work)

| Attempt | Rationale | Result | Why It Failed |
|---|---|---|---|
| tokio::Mutex → std::Mutex | Avoid async mutex issues | No change | Problem wasn't async mutex |
| tokio::sleep → std::thread::sleep | Remove tokio scheduler dependency | No change | Problem wasn't scheduling |
| Move loop to std::thread | Complete isolation from async | No change | Deadlock was in std::sync::Mutex |
| PHASE checkpoints | Find exact hang location | Logs suppressed | journald rate limiting |
| Reduce checkpoint frequency | Avoid suppression | Still unclear | Hang location between checkpoints |
| GDB thread dump | See what threads are doing | **SUCCESS** | Showed mutex contention |

## Lessons Learned

### 1. GDB is the Right Tool for Deadlocks

Checkpoint logging is useful for understanding control flow, but for deadlocks, you need to see thread state. `gdb -batch -ex 'thread apply all bt'` immediately showed the blocked mutex.

### 2. Be Suspicious of Third-Party Library Threading

The rerun SDK's internal use of rayon was not obvious. When debugging mutex issues, check if any called code might spawn threads or use thread pools internally.

### 3. Minimize Critical Section Duration

The original code held the mutex while:
- Building telemetry structs
- Sending to channels
- Recording to rerun
- Updating costmap

Only motor commands and shared state updates truly needed the lock.

### 4. journald Rate Limiting Hides Bugs

High-frequency logging gets suppressed. For debugging timing-critical code:
- Use GDB for thread state
- Write to a file instead of journald
- Use a separate monitoring thread (like our heartbeat)

### 5. Heartbeat Threads Are Valuable

The heartbeat thread immediately confirmed the loop was stuck vs. just slow. This pattern should be standard for safety-critical loops:

```rust
let heartbeat_counter = Arc::new(AtomicU64::new(0));
let counter_clone = heartbeat_counter.clone();

std::thread::spawn(move || {
    let mut last = 0;
    loop {
        std::thread::sleep(Duration::from_secs(5));
        let current = counter_clone.load(Ordering::Relaxed);
        if current == last {
            eprintln!("HEARTBEAT: Loop STUCK at iteration {}", current);
        } else {
            eprintln!("HEARTBEAT: Loop running, iterations: {} (+{})", current, current - last);
        }
        last = current;
    }
});
```

### 6. This Is a Known Rayon Issue

The deadlock pattern we hit is documented in [rayon-rs/rayon#592](https://github.com/rayon-rs/rayon/issues/592). When debugging similar issues, check if any dependency uses rayon (search `Cargo.lock` for `rayon`).

## Reproduction Attempts

We attempted to create a minimal reproduction on macOS x86_64 but could not trigger the deadlock. The issue appears to be specific to Linux aarch64, possibly due to:

1. **Futex implementation**: Linux uses futexes for mutex implementation
2. **ARM64 memory model**: Weaker memory ordering than x86_64
3. **Thread scheduling**: Linux CFS scheduler behavior
4. **Timing-dependent**: Required specific load from WebRTC + LiDAR

The reproduction code is in `/tmp/rerun-deadlock-repro/` for future investigation.

## Action Items

- [x] Fix the deadlock by removing rerun call from critical section
- [x] Clean up debug checkpoints
- [x] Keep heartbeat monitoring for future debugging
- [x] Document root cause (rayon#592)
- [x] Submit docs PR to rerun warning about mutex + rayon pattern (https://github.com/rerun-io/rerun/pull/12579)
- [ ] Move LiDAR recording to async task (recording currently disabled)
- [ ] Audit other recorder calls for similar issues
- [ ] Consider lock-free communication patterns for telemetry
- [ ] Add integration test that runs WebRTC + LiDAR for extended period

## Appendix: GDB Thread Dump (Key Sections)

```
Thread 17 (Thread 0x7f8877fff640 (LWP 77488) "tokio-runtime-w"):
#0  syscall () at ../sysdeps/unix/sysv/linux/aarch64/syscall.S:38
#1  std::sys::sync::mutex::futex::Mutex::lock_contended ()
#2  std::sys::sync::mutex::futex::Mutex::lock ()
#3  std::sync::mutex::Mutex<T>::lock ()
#4  bvrd::main::{{closure}}::{{closure}} ()
    at bins/bvrd/src/main.rs:2337

Thread 10 (Thread 0x7f88e57fe640 (LWP 77481) "tokio-runtime-w"):
#0  syscall () at ../sysdeps/unix/sysv/linux/aarch64/syscall.S:38
#1  parking_lot_core::parking_lot::park ()
#2  rayon_core::sleep::Sleep::sleep ()
#3  rayon_core::registry::WorkerThread::wait_until_cold ()

Thread 11-13: Similar rayon worker stacks
```

The control loop (Thread 17) was blocked on `Mutex::lock_contended` at line 2337, which was inside the LiDAR processing section that called into the rerun SDK.

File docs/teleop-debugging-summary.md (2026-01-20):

# Teleop Debugging Summary

**Date:** 2025-01-19/20
**Rover:** frog-0 (Jetson Orin NX)
**Console:** depot/console React app

---

## Original Problem

When using the depot console to teleoperate frog-0, controls are **extremely jerky**. Holding forward causes the rover to start/stop erratically. The motors work (verified via VESC Tool), but commands arrive in bursts with large gaps (700ms+), causing the watchdog to timeout repeatedly.

---

## Root Causes Identified & Fixed

### 1. Camera/GStreamer Spinloop (FIXED)
**Symptom:** Jetson freezes completely within seconds of starting bvrd with camera enabled.
**Root Cause:** `nvarguscamerasrc` GStreamer pipeline causes 100% CPU spinloop on the Jetson.
**Fix:** Run with `--no-camera` flag until camera pipeline is debugged separately.
**Status:** ✅ Workaround in place

### 2. CAN Bus Driver Overwhelm (FIXED)
**Symptom:** When VESCs are powered off or CAN bus has errors, bvrd would spam the SocketCAN driver at 400 frames/sec, eventually causing system instability.
**Root Cause:** No backoff when CAN errors occur.
**Fix:** Added CAN bus health monitoring with exponential backoff in `bvrd/src/main.rs`:
- Track consecutive CAN errors
- After 10 consecutive errors, back off to 1 retry per second
- Log state transitions (healthy → unhealthy → recovered)
**File:** `bvr/firmware/bins/bvrd/src/main.rs` (lines ~1000-1100)
**Status:** ✅ Fixed

### 3. CAN Backoff Log Spam (FIXED)
**Symptom:** "CAN bus unhealthy" warning logged every 16ms instead of once.
**Root Cause:** Check used `>=` threshold which stayed true; needed a flag to log once.
**Fix:** Added `can_backoff_active` flag to ensure warning logs only once.
**File:** `bvr/firmware/bins/bvrd/src/main.rs`
**Status:** ✅ Fixed

### 4. Keyboard Input Tracking Bug (FIXED)
**Symptom:** Keys appeared to "release" while still held, causing jerky movement.
**Root Cause:** Module-level and useEffect both registered the same `handleKeyUp` function. When useEffect cleanup ran, it removed the shared function entirely.
**Fix:** Separated into `globalKeyUp` (module-level, never removed) and component-level handler.
**File:** `depot/console/src/hooks/useKeyboard.ts`
**Status:** ✅ Fixed

### 5. Discovery Address Issue (FIXED)
**Symptom:** Console couldn't connect to frog-0 via discovery service.
**Root Cause:** bvrd was registering with local network IP (`10.104.17.0`) instead of Tailscale-resolvable hostname.
**Fix:** Added `advertise_host` config option to discovery client. Set to `"frog-0"` in config.
**Files:**
- `bvr/firmware/crates/metrics/src/discovery.rs` - Added `advertise_host: Option<String>` field
- `bvr/firmware/bins/bvrd/src/main.rs` - Wire up config
- `/etc/bvr/bvr.toml` on frog-0 - Set `advertise_host = "frog-0"`
**Status:** ✅ Fixed

### 6. Browser Main Thread Blocking (FIXED)
**Symptom:** Commands sent in bursts with 100-600ms gaps despite 33ms setInterval.
**Root Cause:** JavaScript `setInterval` runs on the main thread, which gets blocked by React re-renders, garbage collection, and other UI work.
**Diagnosis:** Added timestamp to Twist commands; measured 26ms network latency but 400ms+ gaps between sends.
**Fix:** Moved command sending to a **Web Worker** which runs on a separate thread.
**Files:**
- `depot/console/src/workers/commandWorker.ts` - New Web Worker
- `depot/console/src/hooks/useRoverConnection.ts` - Updated to use worker
- `depot/console/src/lib/protocol.ts` - Added timestamp to Twist command (26 bytes now)
- `bvr/firmware/crates/teleop/src/ws.rs` - Added timestamp parsing and gap logging
**Status:** ✅ Fixed (gap_ms now 19-40ms when working correctly)

---

## Remaining Issues

### 1. Multiple WebSocket Connections
**Symptom:** Logs show 3-4 different `cmd_count` values at the same timestamp, indicating multiple clients.
**Evidence:**
```
WebSocket client connected addr=100.108.233.98:53069
WebSocket client connected addr=10.104.12.233:41326
WebSocket client connected addr=10.104.12.233:41328
WebSocket client connected addr=100.108.233.98:53344
```
**Likely Causes:**
- Multiple browser tabs open to console
- Multiple devices (phone, laptop) connected
- Console creating duplicate connections on re-renders
- React StrictMode double-mounting (dev only)

**Impact:** Commands from multiple clients compete, causing jerky behavior even with correct timing.

**Potential Fix:**
- Add connection management to only allow one active teleop session per rover
- Or ensure console properly closes old connections before creating new ones

### 2. Occasional Large Gaps (1-3 seconds)
**Symptom:** Even with Web Worker, occasional gaps of 1000-3000ms appear.
**Likely Causes:**
- Network issues (Tailscale tunnel, WiFi)
- TCP buffering/congestion
- Browser tab throttling when not focused
- Multiple connections interfering

### 3. Clock Skew (Cosmetic)
**Symptom:** `latency_ms` shows 60-90 seconds instead of realistic values.
**Cause:** Browser clock differs from frog-0 clock by ~60-90 seconds.
**Impact:** None functional; just confuses latency metrics.
**Fix:** Could use NTP sync or relative timing instead of absolute timestamps.

### 4. Jetson Freeze After ~13 Minutes (UNRESOLVED)
**Symptom:** frog-0 freezes after running bvrd for extended periods, even with `--no-camera`.
**Likely Causes:**
- SLAM processing (enabled, using LiDAR)
- Rerun recording memory accumulation
- Tokio runtime issue
- Memory leak somewhere

**Not yet investigated.**

---

## Current Configuration

### bvrd on frog-0
```bash
sudo /usr/local/bin/bvrd --no-camera --no-recording --config /etc/bvr/bvr.toml
```

### Key Config (`/etc/bvr/bvr.toml`)
```toml
[discovery]
enabled = true
endpoint = "depot:4860"
rover_id = "frog-0"
rover_name = "Frog-0"
ws_port = 4850
ws_video_port = 4851
heartbeat_secs = 2
advertise_host = "frog-0"  # Use Tailscale hostname
```

### Console
- Dev server: `npm run dev` in `depot/console`
- Commands sent via Web Worker at 30Hz
- Input state polled at 60Hz from main thread

---

## Files Modified

| File | Changes |
|---|---|
| `bvr/firmware/bins/bvrd/src/main.rs` | CAN backoff, discovery config, log filter for teleop |
| `bvr/firmware/crates/metrics/src/discovery.rs` | Added `advertise_host` option |
| `bvr/firmware/crates/teleop/src/ws.rs` | Added timestamp parsing, gap/latency logging |
| `depot/console/src/hooks/useRoverConnection.ts` | Refactored to use Web Worker |
| `depot/console/src/hooks/useKeyboard.ts` | Fixed key tracking bug |
| `depot/console/src/workers/commandWorker.ts` | New file - Web Worker for commands |
| `depot/console/src/lib/protocol.ts` | Added timestamp to Twist command |

---

## Diagnostic Commands

### Check bvrd logs for timing issues:
```bash
ssh frog-0 "grep -E '(gap|latency|client connected)' /tmp/bvrd.log | tail -50"
```

### Check for multiple connections:
```bash
ssh frog-0 "grep 'client connected' /tmp/bvrd.log"
```

### Monitor real-time:
```bash
ssh frog-0 "tail -f /tmp/bvrd.log" | grep -E '(gap|latency)'
```

### Check discovery service:
```bash
curl -s http://depot:4860/rovers | jq
```

---

## Next Steps

1. **Fix multiple connections issue** - Either at console level (ensure single connection) or bvrd level (reject/replace old connections)

2. **Investigate 13-minute freeze** - Run with `RUST_BACKTRACE=1`, check memory usage over time, try disabling SLAM

3. **Fix camera pipeline** - Debug GStreamer/nvarguscamerasrc spinloop separately

4. **Consider UDP instead of WebSocket** - UDP has no TCP buffering/head-of-line blocking issues, better for real-time control

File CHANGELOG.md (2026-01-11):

# Changelog

All notable changes to this project will be documented in this file.

The format is based on [Keep a Changelog](https://keepachangelog.com/en/1.1.0/),
and this project adheres to [Semantic Versioning](https://semver.org/spec/v2.0.0.html).

## [Unreleased]

### Added

#### Dispatch System (Mission Planning & Task Execution)

A complete dispatch system for automated mission planning and task execution across the rover fleet.

**Depot Services**:
- Dispatch service (`depot/dispatch/`) - Rust Axum service on port 4890 for centralized mission management
- PostgreSQL database for persistent storage of zones, missions, and tasks
- WebSocket endpoints for real-time rover communication (`/ws`) and console updates (`/ws/console`)
- Zone CRUD API supporting waypoint routes and GPS polygons
- Mission CRUD API with schedule management and rover assignment
- Task lifecycle management (pending -> assigned -> active -> completed/failed)

**Console Frontend**:
- Dispatch view (`depot/console/src/views/DispatchView.tsx`) for zone/mission management
- Real-time task monitoring with WebSocket updates
- Zone editor for waypoint and polygon definition
- Mission scheduler with rover assignment
- Navigation link in sidebar

**Rover Firmware**:
- Dispatch client crate (`bvr/firmware/crates/dispatch/`) for WebSocket communication with depot
- Auto-reconnect with exponential backoff
- Task assignment handling with automatic mode transition to Autonomous
- Waypoint navigation using dispatched coordinates
- Progress reporting as waypoints are reached (percent, waypoint index, lap count)
- Task completion and failure reporting

**Configuration**:
- `[dispatch]` section in `bvr.toml` for endpoint configuration
- `--no-dispatch` and `--dispatch-endpoint` CLI flags for bvrd
- Docker Compose updates with PostgreSQL and dispatch service

**Data Flow**:
```
Console -> Dispatch Service -> Database -> WebSocket -> Rover
                                               |
Rover executes waypoints <- Task assigned <---+
       |
       +---> Progress/Complete/Failed ---> Dispatch Service ---> Console
```

**Key Files**:
- `depot/dispatch/src/main.rs` - Dispatch service implementation
- `depot/dispatch/migrations/001_initial.sql` - Database schema
- `depot/console/src/views/DispatchView.tsx` - Mission planning UI
- `depot/console/src/hooks/useDispatch.ts` - API client and WebSocket hook
- `bvr/firmware/crates/dispatch/src/lib.rs` - Rover dispatch client
- `bvr/firmware/bins/bvrd/src/main.rs` - Dispatch integration in daemon (lines 577-596, 945-1003, 1023-1150)

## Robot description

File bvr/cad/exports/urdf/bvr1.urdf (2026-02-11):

<?xml version="1.0" encoding="UTF-8"?>
<robot name="bvr1">

  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

  <link name="base_footprint"/>

  <joint name="base_footprint_to_base" type="fixed">
    <parent link="base_footprint"/>
    <child link="base_link"/>
    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
    <origin xyz="0 0 0.0825" rpy="0 0 0"/>
  </joint>

  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

  <link name="base_link">
    <inertial>
      <mass value="14.0"/>
      <origin xyz="0 0 0.0" rpy="0 0 0"/>
      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
    </inertial>
  </link>

  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

  <joint name="base_to_chassis" type="fixed">
    <parent link="base_link"/>
    <child link="chassis_link"/>
    <origin xyz="0 0 0" rpy="0 0 0"/>
  </joint>

  <link name="chassis_link">
    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
  </link>

  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
  <joint name="wheel_fl_joint" type="continuous">
    <parent link="base_link"/>
    <child link="wheel_fl_link"/>
    <origin xyz="0.275 0.275 0" rpy="-1.5708 0 0"/>
    <axis xyz="0 0 1"/>
  </joint>

  <link name="wheel_fl_link">
    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
    <inertial>
      <mass value="1.0"/>
      <origin xyz="0 0 0" rpy="0 0 0"/>
      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
    </inertial>
  </link>

  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
  <joint name="wheel_fr_joint" type="continuous">
    <parent link="base_link"/>
    <child link="wheel_fr_link"/>
    <origin xyz="0.275 -0.275 0" rpy="-1.5708 0 0"/>
    <axis xyz="0 0 1"/>
  </joint>

  <link name="wheel_fr_link">
    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
    <inertial>
      <mass value="1.0"/>
      <origin xyz="0 0 0" rpy="0 0 0"/>
      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
    </inertial>
  </link>

  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
  <joint name="wheel_rl_joint" type="continuous">
    <parent link="base_link"/>
    <child link="wheel_rl_link"/>
    <origin xyz="-0.275 0.275 0" rpy="-1.5708 0 0"/>
    <axis xyz="0 0 1"/>
  </joint>

  <link name="wheel_rl_link">
    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
    <inertial>
      <mass value="1.0"/>
      <origin xyz="0 0 0" rpy="0 0 0"/>
      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
    </inertial>
  </link>

  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
  <joint name="wheel_rr_joint" type="continuous">
    <parent link="base_link"/>
    <child link="wheel_rr_link"/>
    <origin xyz="-0.275 -0.275 0" rpy="-1.5708 0 0"/>
    <axis xyz="0 0 1"/>
  </joint>

  <link name="wheel_rr_link">
    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
    <inertial>
      <mass value="1.0"/>
      <origin xyz="0 0 0" rpy="0 0 0"/>
      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
    </inertial>
  </link>

  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

  <joint name="sensor_mast_joint" type="fixed">
    <parent link="base_link"/>
    <child link="sensor_mast_link"/>
    <origin xyz="0 0 0.29" rpy="0 0 0"/>
  </joint>

  <link name="sensor_mast_link">
    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
    <inertial>
      <mass value="1.0"/>
      <origin xyz="0 0 0" rpy="0 0 0"/>
      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
    </inertial>
  </link>

  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

  <joint name="lidar_joint" type="fixed">
    <parent link="sensor_mast_link"/>
    <child link="lidar_link"/>
    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
    <origin xyz="0 0 0.0475" rpy="0 0.5236 0"/>
  </joint>

  <link name="lidar_link">
    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
    <inertial>
      <mass value="0.5"/>
      <origin xyz="0 0 0" rpy="0 0 0"/>
      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
    </inertial>
  </link>

  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

  <joint name="imu_joint" type="fixed">
    <parent link="base_link"/>
    <child link="imu_link"/>
    <origin xyz="0 0 0.3375" rpy="0 0.5236 0"/>
  </joint>

  <link name="imu_link">
    <inertial>
      <mass value="0.01"/>
      <origin xyz="0 0 0" rpy="0 0 0"/>
      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
    </inertial>
  </link>

  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

  <joint name="camera_joint" type="fixed">
    <parent link="sensor_mast_link"/>
    <child link="camera_link"/>
    <origin xyz="0 0 0.10" rpy="0 0 0"/>
  </joint>

  <link name="camera_link">
    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
    <inertial>
      <mass value="0.3"/>
      <origin xyz="0 0 0" rpy="0 0 0"/>
      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
    </inertial>
  </link>

  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

  <joint name="gps_joint" type="fixed">
    <parent link="sensor_mast_link"/>
    <child link="gps_link"/>
    <origin xyz="0.08 0 0.15" rpy="0 0 0"/>
  </joint>

  <link name="gps_link">
    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
    <inertial>
      <mass value="0.1"/>
      <origin xyz="0 0 0" rpy="0 0 0"/>
      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
    </inertial>
  </link>

  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

</robot>

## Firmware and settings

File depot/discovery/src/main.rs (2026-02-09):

//! Rover Discovery Service
//!
//! A lightweight service that tracks rover presence and provides
//! a WebSocket API for operators to discover available rovers.
//!
//! Endpoints:
//! - POST /register - Rovers register with their info
//! - POST /heartbeat/:id - Rovers send heartbeats with telemetry
//! - GET /rovers - List all known rovers (HTTP fallback)
//! - GET /ws - WebSocket for live rover updates
//! - GET /health - Health check
//! - GET /api/sessions - List all recorded sessions
//! - GET /api/sessions/:rover_id/:session_dir/session.rrd - Serve session file

use axum::{
    body::Body,
    extract::{
        ws::{Message, WebSocket, WebSocketUpgrade},
        Path, Query, State,
    },
    http::{header, StatusCode},
    response::IntoResponse,
    routing::{get, post},
    Json, Router,
};
use futures_util::{SinkExt, StreamExt};
use serde::{Deserialize, Serialize};
use std::{
    collections::HashMap,
    net::SocketAddr,
    path::PathBuf,
    sync::Arc,
    time::{Duration, Instant},
};
use tokio::sync::{broadcast, RwLock};
use tokio_util::io::ReaderStream;
use tower_http::cors::CorsLayer;
use tracing::{debug, info, warn};

/// Rover timeout - rovers go offline after this duration without heartbeat
const ROVER_TIMEOUT: Duration = Duration::from_secs(10);

/// Pose in 2D space
#[derive(Debug, Clone, Serialize, Deserialize, Default)]
struct Pose {
    x: f64,
    y: f64,
    theta: f64,
}

/// Rover information stored in registry
#[derive(Debug, Clone, Serialize)]
#[serde(rename_all = "camelCase")]
struct RoverInfo {
    id: String,
    name: String,
    /// WebRTC signaling address (e.g., "ws://192.168.1.100:4852")
    rtc_address: String,
    online: bool,
    battery_voltage: f64,
    last_pose: Pose,
    mode: u8,
    last_seen: u64, // Unix timestamp in milliseconds
    #[serde(skip)]
    last_seen_instant: Instant,
}

/// Registration payload from rovers
#[derive(Debug, Deserialize)]
struct RegisterPayload {
    id: String,
    name: String,
    /// WebRTC signaling address (e.g., "ws://192.168.1.100:4852")
    rtc_address: String,
    battery_voltage: Option<f64>,
    mode: Option<u8>,
    pose: Option<Pose>,
}

/// Heartbeat payload from rovers
#[derive(Debug, Deserialize)]
struct HeartbeatPayload {
    battery_voltage: Option<f64>,
    mode: Option<u8>,
    pose: Option<Pose>,
}

/// WebSocket message to operators
#[derive(Debug, Serialize)]
struct WsMessage {
    #[serde(rename = "type")]
    msg_type: String,
    data: Vec<RoverInfo>,
}

// =============================================================================
// Session Types (matching recording crate's SessionMetadata)
// =============================================================================

/// GPS bounding box for a session
#[derive(Debug, Clone, Serialize, Deserialize)]
struct GpsSessionBounds {
    min_lat: f64,
    max_lat: f64,
    min_lon: f64,
    max_lon: f64,
}

/// Session metadata (read from metadata.json)
#[derive(Debug, Clone, Serialize, Deserialize)]
struct SessionMetadata {
    session_id: String,
    rover_id: String,
    started_at: String,
    ended_at: Option<String>,
    #[serde(default)]
    duration_secs: f64,
    gps_bounds: Option<GpsSessionBounds>,
    lidar_frames: u32,
    camera_frames: u32,
    #[serde(default)]
    pose_samples: u32,
    session_file: String,
    /// Added by API: the directory name
    #[serde(default)]
    session_dir: String,
}

/// Query params for sessions list
#[derive(Debug, Deserialize)]
struct SessionsQuery {
    rover_id: Option<String>,
}

/// Response for sessions list
#[derive(Debug, Serialize)]
struct SessionsResponse {
    sessions: Vec<SessionMetadata>,
}

/// Shared application state
struct AppState {
    rovers: RwLock<HashMap<String, RoverInfo>>,
    broadcast_tx: broadcast::Sender<()>,
    /// Base directory for session data (contains rover subdirectories)
    sessions_dir: PathBuf,
}

impl AppState {
    fn new(sessions_dir: PathBuf) -> Self {
        let (broadcast_tx, _) = broadcast::channel(16);
        Self {
            rovers: RwLock::new(HashMap::new()),
            broadcast_tx,
            sessions_dir,
        }
    }

    /// Get current rover list with online status updated
    async fn get_rovers(&self) -> Vec<RoverInfo> {
        let rovers = self.rovers.read().await;
        let now = Instant::now();

        rovers
            .values()
            .map(|r| {
                let mut rover = r.clone();
                rover.online = now.duration_since(r.last_seen_instant) < ROVER_TIMEOUT;
                rover
            })
            .collect()
    }

    /// Notify all WebSocket clients of an update
    fn notify(&self) {
        let _ = self.broadcast_tx.send(());
    }
}

type SharedState = Arc<AppState>;

#[tokio::main]
async fn main() {
    // Initialize logging
    let env_filter = tracing_subscriber::EnvFilter::try_from_default_env()
        .unwrap_or_else(|_| "discovery=info".into());

    if std::env::var("RUST_LOG_FORMAT").as_deref() == Ok("json") {
        tracing_subscriber::fmt()
            .json()
            .with_env_filter(env_filter)
            .init();
    } else {
        tracing_subscriber::fmt()
            .with_env_filter(env_filter)
            .init();
    }

    // Sessions directory (where synced rover data lives)
    let sessions_dir = std::env::var("SESSIONS_DIR")
        .map(PathBuf::from)
        .unwrap_or_else(|_| PathBuf::from("/data/sessions"));

    info!(path = %sessions_dir.display(), "Sessions directory");

    let state = Arc::new(AppState::new(sessions_dir));

    // Spawn background task to check for stale rovers
    let state_clone = state.clone();
    tokio::spawn(async move {
        let mut interval = tokio::time::interval(Duration::from_secs(2));
        loop {
            interval.tick().await;

            let mut changed = false;
            {
                let rovers = state_clone.rovers.read().await;
                let now = Instant::now();
                for rover in rovers.values() {
                    let was_online = now.duration_since(rover.last_seen_instant) < ROVER_TIMEOUT;
                    // We just check; actual update happens on next get_rovers() call
                    if !was_online && rover.online {
                        changed = true;
                    }
                }
            }

            if changed {
                state_clone.notify();
            }
        }
    });

    let app = Router::new()
        .route("/register", post(register))
        .route("/heartbeat/{id}", post(heartbeat))
        .route("/rovers", get(list_rovers))
        .route("/ws", get(ws_handler))
        .route("/health", get(health))
        // Sessions API
        .route("/api/sessions", get(list_sessions))
        .route(
            "/api/sessions/{rover_id}/{session_dir}/session.rrd",
            get(serve_session_rrd),
        )
        .layer(CorsLayer::permissive())
        .with_state(state);

    let port: u16 = std::env::var("PORT")
        .ok()
        .and_then(|p| p.parse().ok())
        .unwrap_or(4860);

    let addr = SocketAddr::from(([0, 0, 0, 0], port));
    info!("Discovery service listening on {}", addr);

    let listener = tokio::net::TcpListener::bind(addr)
        .await
        .expect("failed to bind to address");
    axum::serve(listener, app)
        .await
        .expect("server exited with error");
}

/// Health check endpoint
async fn health(State(state): State<SharedState>) -> impl IntoResponse {
    let count = state.rovers.read().await.len();
    Json(serde_json::json!({
        "status": "ok",
        "rovers": count
    }))
}

/// Register a new rover
async fn register(
    State(state): State<SharedState>,
    Json(payload): Json<RegisterPayload>,
) -> impl IntoResponse {
    let now = Instant::now();
    let now_ms = std::time::SystemTime::now()
        .duration_since(std::time::UNIX_EPOCH)
        .unwrap()
        .as_millis() as u64;

    let rover = RoverInfo {
        id: payload.id.clone(),
        name: payload.name.clone(),
        rtc_address: payload.rtc_address.clone(),
        online: true,
        battery_voltage: payload.battery_voltage.unwrap_or(0.0),
        last_pose: payload.pose.unwrap_or_default(),
        mode: payload.mode.unwrap_or(0),
        last_seen: now_ms,
        last_seen_instant: now,
    };

    let is_new = {
        let mut rovers = state.rovers.write().await;
        let is_new = !rovers.contains_key(&payload.id);
        rovers.insert(payload.id.clone(), rover);
        is_new
    };

    info!(
        id = %payload.id,
        name = %payload.name,
        rtc_address = %payload.rtc_address,
        new = is_new,
        "Rover registered"
    );

    state.notify();

    (StatusCode::OK, Json(serde_json::json!({ "ok": true })))
}

/// Heartbeat from a rover
async fn heartbeat(
    State(state): State<SharedState>,
    Path(id): Path<String>,
    Json(payload): Json<HeartbeatPayload>,
) -> impl IntoResponse {
    let now = Instant::now();
    let now_ms = std::time::SystemTime::now()
        .duration_since(std::time::UNIX_EPOCH)
        .unwrap()
        .as_millis() as u64;

    let mut rovers = state.rovers.write().await;

    if let Some(rover) = rovers.get_mut(&id) {
        rover.last_seen = now_ms;
        rover.last_seen_instant = now;
        rover.online = true;

        if let Some(v) = payload.battery_voltage {
            rover.battery_voltage = v;
        }
        if let Some(m) = payload.mode {
            rover.mode = m;
        }
        if let Some(p) = payload.pose {
            rover.last_pose = p;
        }

        drop(rovers);
        state.notify();

        (StatusCode::OK, Json(serde_json::json!({ "ok": true })))
    } else {
        warn!(id = %id, "Heartbeat for unknown rover");
        (
            StatusCode::NOT_FOUND,
            Json(serde_json::json!({ "error": "Rover not found" })),
        )
    }
}

/// List all rovers (HTTP fallback)
async fn list_rovers(State(state): State<SharedState>) -> impl IntoResponse {
    let rovers = state.get_rovers().await;
    Json(rovers)
}

/// WebSocket handler for live updates
async fn ws_handler(
    ws: WebSocketUpgrade,
    State(state): State<SharedState>,
) -> impl IntoResponse {
    ws.on_upgrade(|socket| handle_ws(socket, state))
}

async fn handle_ws(socket: WebSocket, state: SharedState) {
    let (mut sender, mut receiver) = socket.split();

    // Subscribe to updates
    let mut rx = state.broadcast_tx.subscribe();

    // Send initial rover list
    let rovers = state.get_rovers().await;
    let msg = WsMessage {
        msg_type: "rovers".to_string(),
        data: rovers,
    };
    if let Ok(json) = serde_json::to_string(&msg) {
        let _ = sender.send(Message::Text(json.into())).await;
    }

    info!("Operator connected via WebSocket");

    loop {
        tokio::select! {
            // Handle broadcast updates
            Ok(()) = rx.recv() => {
                let rovers = state.get_rovers().await;
                let msg = WsMessage {
                    msg_type: "rovers".to_string(),
                    data: rovers,
                };
                if let Ok(json) = serde_json::to_string(&msg) {
                    if sender.send(Message::Text(json.into())).await.is_err() {
                        break;
                    }
                }
            }

            // Handle incoming messages (for ping/pong, etc.)
            msg = receiver.next() => {
                match msg {
                    Some(Ok(Message::Close(_))) | None => break,
                    Some(Ok(Message::Ping(data))) => {
                        let _ = sender.send(Message::Pong(data)).await;
                    }
                    _ => {}
                }
            }
        }
    }

    info!("Operator disconnected");
}

// =============================================================================
// Sessions API
// =============================================================================

/// List all recorded sessions
///
/// Scans the sessions directory for all rovers and returns session metadata.
/// Sessions are read from metadata.json files in each session directory.
async fn list_sessions(
    State(state): State<SharedState>,
    Query(query): Query<SessionsQuery>,
) -> impl IntoResponse {
    let mut sessions: Vec<SessionMetadata> = Vec::new();

    // Check if sessions directory exists
    if !state.sessions_dir.exists() {
        debug!(
            path = %state.sessions_dir.display(),
            "Sessions directory does not exist"
        );
        return Json(SessionsResponse { sessions });
    }

    // Iterate over rover directories
    let rover_dirs = match std::fs::read_dir(&state.sessions_dir) {
        Ok(dirs) => dirs,
        Err(e) => {
            warn!(error = %e, "Failed to read sessions directory");
            return Json(SessionsResponse { sessions });
        }
    };

    for rover_entry in rover_dirs.filter_map(|e| e.ok()) {
        let rover_path = rover_entry.path();
        if !rover_path.is_dir() {
            continue;
        }

        let rover_id = rover_path
            .file_name()
            .and_then(|n| n.to_str())
            .unwrap_or("")
            .to_string();

        // Filter by rover_id if specified
        if let Some(ref filter_id) = query.rover_id {
            if &rover_id != filter_id {
                continue;
            }
        }

        // Look for sessions directory under rover (synced structure: /data/sessions/{rover_id}/sessions/...)
        let sessions_path = rover_path.join("sessions");
        let search_path = if sessions_path.exists() {
            sessions_path
        } else {
            rover_path.clone()
        };

        // Iterate over session directories
        let session_dirs = match std::fs::read_dir(&search_path) {
            Ok(dirs) => dirs,
            Err(_) => continue,
        };

        for session_entry in session_dirs.filter_map(|e| e.ok()) {
            let session_path = session_entry.path();
            if !session_path.is_dir() {
                continue;
            }

            let session_dir = session_path
                .file_name()
                .and_then(|n| n.to_str())
                .unwrap_or("")
                .to_string();

            // Read metadata.json
            let metadata_path = session_path.join("metadata.json");
            if !metadata_path.exists() {
                continue;
            }

            match std::fs::read_to_string(&metadata_path) {
                Ok(content) => match serde_json::from_str::<SessionMetadata>(&content) {
                    Ok(mut metadata) => {
                        metadata.session_dir = session_dir;
                        sessions.push(metadata);
                    }
                    Err(e) => {
                        debug!(
                            path = %metadata_path.display(),
                            error = %e,
                            "Failed to parse session metadata"
                        );
                    }
                },
                Err(e) => {
                    debug!(
                        path = %metadata_path.display(),
                        error = %e,
                        "Failed to read session metadata"
                    );
                }
            }
        }
    }

    // Sort by start time, newest first
    sessions.sort_by(|a, b| b.started_at.cmp(&a.started_at));

    info!(count = sessions.len(), "Listed sessions");
    Json(SessionsResponse { sessions })
}

/// Serve a session's RRD file
///
/// Streams the session.rrd file for viewing in Rerun.
async fn serve_session_rrd(
    State(state): State<SharedState>,
    Path((rover_id, session_dir)): Path<(String, String)>,
) -> impl IntoResponse {
    // Build the path to the session file
    // Try both direct and nested structures:
    // - /data/sessions/{rover_id}/{session_dir}/session.rrd
    // - /data/sessions/{rover_id}/sessions/{session_dir}/session.rrd
    let direct_path = state
        .sessions_dir
        .join(&rover_id)
        .join(&session_dir)
        .join("session.rrd");
    let nested_path = state
        .sessions_dir
        .join(&rover_id)
        .join("sessions")
        .join(&session_dir)
        .join("session.rrd");

    let rrd_path = if direct_path.exists() {
        direct_path
    } else if nested_path.exists() {
        nested_path
    } else {
        warn!(
            rover_id = %rover_id,
            session_dir = %session_dir,
            "Session RRD file not found"
        );
        return Err((StatusCode::NOT_FOUND, "Session not found"));
    };

    // Open the file
    let file = match tokio::fs::File::open(&rrd_path).await {
        Ok(f) => f,
        Err(e) => {
            warn!(
                path = %rrd_path.display(),
                error = %e,
                "Failed to open session file"
            );
            return Err((StatusCode::INTERNAL_SERVER_ERROR, "Failed to read session"));
        }
    };

    // Get file size for Content-Length
    let metadata = match file.metadata().await {
        Ok(m) => m,
        Err(_) => {
            return Err((StatusCode::INTERNAL_SERVER_ERROR, "Failed to read file metadata"));
        }
    };

    let file_size = metadata.len();
    info!(
        path = %rrd_path.display(),
        size = file_size,
        "Serving session RRD"
    );

    // Stream the file
    let stream = ReaderStream::new(file);
    let body = Body::from_stream(stream);

    Ok((
        [
            (header::CONTENT_TYPE, "application/octet-stream"),
            (
                header::CONTENT_DISPOSITION,
                "attachment; filename=\"session.rrd\"",
            ),
            // Allow cross-origin requests for Rerun viewer
            (header::ACCESS_CONTROL_ALLOW_ORIGIN, "*"),
        ],
        body,
    ))
}

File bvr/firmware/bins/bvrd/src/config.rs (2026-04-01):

//! Configuration file structures for bvr.toml.

use anyhow::Result;
use serde::Deserialize;
use tools::blower::BlowerConfig;
use tools::eth_protocol;
use tracing::warn;

/// Configuration file structure (bvr.toml).
#[derive(Debug, Deserialize, Default)]
#[serde(default)]
pub(crate) struct FileConfig {
    pub identity: IdentityConfig,
    pub chassis: ChassisFileConfig,
    pub control: ControlFileConfig,
    pub metrics: MetricsFileConfig,
    pub discovery: DiscoveryFileConfig,
    pub autonomous: AutonomousFileConfig,
    pub dispatch: DispatchFileConfig,
    pub lidar: LidarFileConfig,
    pub localization: LocalizationFileConfig,
    pub slam: SlamFileConfig,
    pub navigation: NavigationFileConfig,
    pub estop: EStopFileConfig,
    pub camera: CameraFileConfig,
    pub blower: BlowerConfig,
    pub eth_tools: EthToolsFileConfig,
    pub collision_guard: CollisionGuardFileConfig,
    pub depth: DepthFileConfig,
}

/// Depth perception configuration (camera-based obstacle detection + visual odometry).
#[derive(Debug, Deserialize)]
#[serde(default)]
pub(crate) struct DepthFileConfig {
    /// Enable depth-based perception pipeline
    pub enabled: bool,
    /// Path to ONNX depth model (Depth Anything V2/V3 Small)
    pub model_path: String,
    /// Model input width (pixels)
    pub model_input_width: u32,
    /// Model input height (pixels)
    pub model_input_height: u32,
    /// Raw capture width for depth inference
    pub capture_width: u32,
    /// Raw capture height for depth inference
    pub capture_height: u32,
    /// Raw capture framerate for depth inference
    pub capture_fps: u32,
    /// Maximum depth to consider (meters)
    pub max_depth: f32,
    /// Minimum depth to consider (meters)
    pub min_depth: f32,
    /// Height threshold for ground classification (meters)
    pub ground_threshold: f32,
    /// Pixel stride for back-projection (higher = faster, fewer points)
    pub stride: u32,
    /// Enable visual odometry (frame-to-frame ICP)
    pub visual_odometry: bool,
    /// ICP maximum correspondence distance (meters)
    pub icp_max_dist: f64,
    /// ICP maximum iterations
    pub icp_max_iterations: usize,
}

impl Default for DepthFileConfig {
    fn default() -> Self {
        Self {
            enabled: false,
            model_path: "/var/lib/bvr/models/depth-anything-v2-small.onnx".to_string(),
            model_input_width: 518,
            model_input_height: 518,
            capture_width: 640,
            capture_height: 480,
            capture_fps: 15,
            max_depth: 8.0,
            min_depth: 0.3,
            ground_threshold: 0.10,
            stride: 4,
            visual_odometry: true,
            icp_max_dist: 0.5,
            icp_max_iterations: 20,
        }
    }
}

/// Control loop configuration.
#[derive(Debug, Deserialize)]
#[serde(default)]
pub(crate) struct ControlFileConfig {
    /// Seconds of inactivity in Idle/Disabled before auto-transitioning to Sleep (0 = disabled)
    pub sleep_timeout_secs: u64,
    /// Watchdog timeout in milliseconds — if no heartbeat/command arrives within this window,
    /// teleop drops to Idle. 1500ms handles browser tab throttling (1Hz setInterval) with margin.
    pub watchdog_timeout_ms: u64,
}

impl Default for ControlFileConfig {
    fn default() -> Self {
        Self {
            sleep_timeout_secs: 0, // disabled by default
            watchdog_timeout_ms: 1500,
        }
    }
}

/// Collision monitor configuration (velocity scaling near obstacles, all modes).
#[derive(Debug, Deserialize)]
#[serde(default)]
pub(crate) struct CollisionGuardFileConfig {
    pub enabled: bool,
    pub lookahead_time: f64,
    pub num_samples: usize,
    pub full_speed_distance: f64,
    pub stop_distance: f64,
    pub cost_threshold: u8,
    pub min_zone_scale: f64,
    pub max_linear_velocity: f64,
    pub num_angular_samples: usize,
    pub angular_spread: f64,
    pub angular_cost_weight: f64,
}

impl Default for CollisionGuardFileConfig {
    fn default() -> Self {
        Self {
            enabled: true,
            lookahead_time: 1.0,
            num_samples: 10,
            full_speed_distance: 1.0,
            stop_distance: 0.15,
            cost_threshold: 253,
            min_zone_scale: 0.5,
            max_linear_velocity: 1.0,
            num_angular_samples: 5,
            angular_spread: 0.5,
            angular_cost_weight: 0.3,
        }
    }
}
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

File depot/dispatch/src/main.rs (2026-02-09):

//! Dispatch Service
//!
//! Mission planning and task assignment for rover fleet operations.
//!
//! Endpoints:
//! - Zone CRUD: POST/GET/PUT/DELETE /zones
//! - Mission CRUD: POST/GET/PUT/DELETE /missions
//! - Mission control: POST /missions/:id/start, POST /missions/:id/stop
//! - Task management: GET /tasks, POST /tasks/:id/cancel
//! - Alerts: GET/POST /api/alerts
//! - Weather: GET /api/weather
//! - Rover commands: GET /rovers, POST /rovers/:id/command
//! - WebSocket: /ws - rovers connect here for task assignment
//! - Health: GET /health

pub mod alerts;
pub mod coverage;
pub mod weather;
pub mod webhook;

use axum::{
    extract::{
        ws::{Message, WebSocket, WebSocketUpgrade},
        Path, Query, State,
    },
    http::{HeaderMap, StatusCode},
    response::IntoResponse,
    routing::{delete, get, post, put},
    Json, Router,
};
use chrono::{DateTime, Utc};
use futures_util::{SinkExt, StreamExt};
use serde::{Deserialize, Serialize};
use sqlx::{postgres::PgPoolOptions, FromRow, PgPool};
use std::{collections::HashMap, net::SocketAddr, sync::Arc};
use tokio::sync::{broadcast, RwLock};
use tower_http::cors::CorsLayer;
use tracing::{info, info_span, warn};
use uuid::Uuid;

// =============================================================================
// Database Models
// =============================================================================

/// Waypoint in a zone
#[derive(Debug, Clone, Serialize, Deserialize)]
pub struct Waypoint {
    pub x: f64,
    pub y: f64,
    #[serde(skip_serializing_if = "Option::is_none")]
    pub theta: Option<f64>,
}

/// Zone record from database
#[derive(Debug, Clone, Serialize, Deserialize, FromRow)]
#[serde(rename_all = "camelCase")]
pub struct Zone {
    pub id: Uuid,
    pub name: String,
    pub zone_type: String,
    #[sqlx(json)]
    pub waypoints: serde_json::Value,
    // Note: no #[sqlx(json)] here - Option<Value> handles nullable JSONB natively
    pub polygon: Option<serde_json::Value>,
    /// Lat/lng polygon for map display (separate from local-frame waypoints)
    pub polygon_latlng: Option<serde_json::Value>,
    pub map_id: Option<Uuid>,
    /// Coverage tool configuration (for coverage zones)
    pub coverage_config: Option<serde_json::Value>,
    /// Generated coverage waypoints (boustrophedon sweep path)
    pub coverage_waypoints: Option<serde_json::Value>,
    pub created_at: DateTime<Utc>,
    pub updated_at: DateTime<Utc>,
}

/// GPS coordinate for outdoor zones
#[derive(Debug, Clone, Serialize, Deserialize)]
pub struct GpsCoord {
    pub lat: f64,
    pub lon: f64,
}

/// Mission schedule configuration
#[derive(Debug, Clone, Serialize, Deserialize, Default)]
pub struct Schedule {
    /// Trigger type: "manual", "once", "cron"
    #[serde(default = "default_trigger")]
    pub trigger: String,
    /// Cron expression (if trigger = "cron")
    #[serde(skip_serializing_if = "Option::is_none")]
    pub cron: Option<String>,
    /// Whether to loop continuously
    #[serde(default)]
    pub r#loop: bool,
}

fn default_trigger() -> String {
    "manual".to_string()
}

/// Mission record from database
#[derive(Debug, Clone, Serialize, Deserialize, FromRow)]
#[serde(rename_all = "camelCase")]
pub struct Mission {
    pub id: Uuid,
    pub name: String,
    pub zone_id: Uuid,
    pub rover_id: Option<String>,
    #[sqlx(json)]
    pub schedule: serde_json::Value,
    pub enabled: bool,
    pub created_at: DateTime<Utc>,
    pub updated_at: DateTime<Utc>,
}

/// Task status
#[derive(Debug, Clone, Copy, PartialEq, Eq, Serialize, Deserialize)]
#[serde(rename_all = "lowercase")]
pub enum TaskStatus {
    Pending,
    Assigned,
    Active,
    Done,
    Failed,
    Cancelled,
}

impl std::fmt::Display for TaskStatus {
    fn fmt(&self, f: &mut std::fmt::Formatter<'_>) -> std::fmt::Result {
        match self {
            TaskStatus::Pending => write!(f, "pending"),
            TaskStatus::Assigned => write!(f, "assigned"),
            TaskStatus::Active => write!(f, "active"),
            TaskStatus::Done => write!(f, "done"),
            TaskStatus::Failed => write!(f, "failed"),
            TaskStatus::Cancelled => write!(f, "cancelled"),
        }
    }
}

impl From<String> for TaskStatus {
    fn from(s: String) -> Self {
        match s.as_str() {
            "pending" => TaskStatus::Pending,
            "assigned" => TaskStatus::Assigned,
            "active" => TaskStatus::Active,
            "done" => TaskStatus::Done,
            "failed" => TaskStatus::Failed,
            "cancelled" => TaskStatus::Cancelled,
            _ => TaskStatus::Pending,
        }
    }
}



/// Task record from database
#[derive(Debug, Clone, Serialize, Deserialize, FromRow)]
#[serde(rename_all = "camelCase")]
pub struct Task {
    pub id: Uuid,
    pub mission_id: Uuid,
    pub rover_id: String,
    pub status: String,
    pub progress: i32,
    pub waypoint: i32,
    pub lap: i32,
    pub error: Option<String>,
    pub created_at: DateTime<Utc>,
    pub started_at: Option<DateTime<Utc>>,
    pub ended_at: Option<DateTime<Utc>>,
}

// =============================================================================
// API Request/Response Types
// =============================================================================

#[derive(Debug, Deserialize)]
#[serde(rename_all = "camelCase")]
pub struct CreateZone {
    pub name: String,
    #[serde(default = "default_zone_type")]
    pub zone_type: String,
    pub waypoints: Vec<Waypoint>,
    pub polygon: Option<Vec<GpsCoord>>,
    /// Lat/lng polygon for map display
    pub polygon_latlng: Option<Vec<[f64; 2]>>,
    pub map_id: Option<Uuid>,
}

fn default_zone_type() -> String {
    "route".to_string()
}

#[derive(Debug, Deserialize)]
#[serde(rename_all = "camelCase")]
pub struct UpdateZone {
    pub name: Option<String>,
    pub zone_type: Option<String>,
    pub waypoints: Option<Vec<Waypoint>>,
    pub polygon: Option<Vec<GpsCoord>>,
    /// Lat/lng polygon for map display
    pub polygon_latlng: Option<Vec<[f64; 2]>>,
    pub map_id: Option<Uuid>,
}

#[derive(Debug, Deserialize)]
#[serde(rename_all = "camelCase")]
pub struct CreateMission {
    pub name: String,
    pub zone_id: Uuid,
    pub rover_id: Option<String>,
    #[serde(default)]
    pub schedule: Schedule,
}

#[derive(Debug, Deserialize)]
#[serde(rename_all = "camelCase")]
pub struct UpdateMission {
    pub name: Option<String>,
    pub zone_id: Option<Uuid>,
    pub rover_id: Option<String>,
    pub schedule: Option<Schedule>,
    pub enabled: Option<bool>,
}

#[derive(Debug, Deserialize)]
#[serde(rename_all = "camelCase")]
pub struct GenerateCoverageRequest {
    pub tool_width: f64,
    pub overlap_pct: f64,
    pub swath_angle: Option<f64>,
}

#[derive(Debug, Deserialize)]
pub struct TasksQuery {
    pub status: Option<String>,
    pub rover_id: Option<String>,
    pub mission_id: Option<Uuid>,
    /// Unix milliseconds — only return tasks created after this time
    pub since: Option<i64>,
}
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

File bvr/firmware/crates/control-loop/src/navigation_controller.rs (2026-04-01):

//! Navigation Controller
//!
//! Integrates path planning (A*) and path following (pure pursuit) with
//! costmap-based obstacle avoidance for autonomous navigation.
//!
//! This replaces the policy-based autonomous controller with a classical
//! navigation stack that supports:
//! - Global path planning with A*
//! - Local path following with pure pursuit
//! - Reactive obstacle detection and stopping
//! - Automatic replanning when path is blocked

use costmap::{Costmap, CostmapSnapshot, Obstacle, ScanAccumulator};
use dispatch::TaskAssignment;
#[cfg(feature = "lidar")]
use lidar::PointCloud;
use mppi::{MppiConfig, MppiController};
use nalgebra::{Vector2, Vector3};
use planner::{PlannerConfig, ReactivePlanner, SmootherConfig, Waypoint};
use pursuit::{PursuitConfig, PursuitController, PursuitError, PursuitOutput};
use std::time::Instant;
use tracing::{debug, error, info, warn};
use transforms::Transform2D;
use types::{Pose, Twist};
use uuid::Uuid;

/// Which local controller to use for path following.
#[derive(Debug, Clone, Copy, PartialEq)]
pub enum ControllerType {
    /// Classical pure pursuit controller (default).
    PurePursuit,
    /// MPPI sampling-based trajectory optimizer.
    Mppi,
}

impl Default for ControllerType {
    fn default() -> Self {
        Self::PurePursuit
    }
}

/// Navigation controller configuration.
#[derive(Debug, Clone)]
pub struct NavigationConfig {
    /// Costmap configuration
    pub costmap_width: f64,  // meters
    pub costmap_height: f64, // meters
    pub costmap_resolution: f64, // meters per cell
    pub inflation_radius: f64,   // meters
    pub inscribed_radius: f64,   // robot footprint radius

    /// Planner configuration
    pub planner: PlannerConfig,

    /// Pursuit configuration
    pub pursuit: PursuitConfig,

    /// MPPI configuration (used when controller_type == Mppi)
    pub mppi: MppiConfig,

    /// Which local controller to use
    pub controller_type: ControllerType,

    /// Replan distance (how close to waypoint before advancing)
    pub replan_distance: f64,

    /// Blocked timeout (seconds) - how long to wait before starting recovery
    pub blocked_timeout: f64,

    /// Path smoother configuration (None to disable smoothing)
    pub smoother: Option<SmootherConfig>,

    /// Recovery behavior configuration
    pub recovery: RecoveryConfig,
}
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

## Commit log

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2025-12-16 Fix controls and add orbit camera to operator station
    Fixes:
    - Wheels now oriented correctly (axles point sideways)
    - Left/right controls now work correctly (A=left, D=right)
    - Rover rotation direction fixed
    Camera improvements:
    - Third-person follow cam (default) - stays behind rover
    - First-person view (press C to toggle)
    - Free look mode (press V to toggle)
    - Mouse: right-click + drag to orbit
    - Gamepad: right stick to orbit
    - Auto-resets behind rover when moving
    [main.rs]
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2025-12-16 Fix sim mode: auto-enable state machine so rover can move
    The rover wasn't moving because:
    - State machine started in Disabled mode
    - Twist commands only work in Teleop mode
    - No transition was happening
    - In sim mode, auto-enable to Idle at startup
    - Auto-transition Disabled→Idle→Teleop when receiving twist commands
    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
    [lib.rs, main.rs]
2025-12-16 Fix telemetry: better initial values and debug logging
    - Initial telemetry now uses actual mode (Idle in sim)
    - Initial battery voltage set to 48V (simulated)
    - Initial motor temps set to 25°C (ambient)
    - Added debug logging for sent telemetry
    - Added error logging for failed sends
    [lib.rs, main.rs]
2025-12-16 Fix teleop: use interval instead of sleep for telemetry
    The previous code used tokio::sleep in a select! which caused
    telemetry to never be sent while commands were flowing:
    - Commands arrive every 25ms
    - sleep(100ms) was reset each iteration
    - recv_from always won the race
    Now using tokio::time::interval which properly tracks elapsed
    time across select iterations. Telemetry will be sent every
    100ms regardless of command frequency.
    [lib.rs]
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2025-12-16 Add camera streaming from bvrd to operator
    - New camera crate: webcam capture via nokhwa, JPEG encoding
    - New teleop video module: chunked UDP protocol for streaming frames
    - bvrd: --camera flag enables capture and streaming on port 4842
    - operator: displays live video feed in egui window
    - Video decoding runs in background thread to avoid blocking render loop
    - CameraMount struct defines fixed camera position for future 3D projection
    [lib.rs, main.rs]
2025-12-16 Rewrite camera crate with GStreamer for cross-platform support
    - Replace nokhwa with GStreamer for camera capture
    - Add auto-detection for CSI (Jetson), USB (Linux), and AVF (macOS) cameras
    - Support multiple camera types with appropriate pipelines
    - Increase default FPS to 30, lower JPEG quality to 60 for lower latency
    - Add platform-specific detection and pipeline building
    [lib.rs]
2025-12-16 Add GPS crate with NMEA parsing and serial reader
    - Parse GGA and RMC sentences for position data
    - Support configurable serial port and baud rate
    - Provide GpsState with coordinates, fix quality, and satellite count
    - Include checksum validation and coordinate conversion
    [lib.rs]
2025-12-16 Add localization crate with wheel odometry and pose estimation
    - WheelOdometry: compute displacement from VESC tachometer readings
    - PoseEstimator: fuse odometry with GPS using complementary filter
    - Support GPS-to-local coordinate conversion for position correction
    [lib.rs]
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2025-12-16 feat(operator): add 3D video frustum display
    Display the video feed projected onto a frustum in the 3D view,
    following the rover's position and orientation. Includes gizmo
    lines showing the camera projection geometry.
    Also fixes video texture flickering by tracking sequence numbers
    separately for the UI update cycle.
    [main.rs]
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2025-12-17 refactor: remove duplicate bvr-prefixed crates
    The non-prefixed crates (can, control, hal, state, teleop, types, cli)
    are more developed and already used by the workspace. Remove the
    duplicate bvr-* variants to avoid confusion and keep codebase DRY.
    [lib.rs, main.rs]
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2025-12-17 feat: add bvr scan command for CAN bus VESC discovery
    - Rename cli binary to bvr for cleaner naming
    - Add scan subcommand to discover VESCs on CAN bus
    - Display ID, ERPM, current, duty, temps, voltage in table
    - Fix socketcan Frame trait import for compatibility
    - Update deploy.sh to use new bvr binary name
    [lib.rs, main.rs]
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2025-12-18 feat(control): add input smoothing and angular boost for skid steering
    - Add exponential moving average filter (α=0.15) to smooth commanded twist
    - Boost angular velocity 2.5x for skid steering torque requirements
    - Increase watchdog timeout to 500ms for Tailscale network jitter
    - Add separate max_decel (6.0) for responsive stopping vs acceleration (2.0)
    - Add debug logging for twist commands and wheel RPMs when turning
    [lib.rs, main.rs]
2025-12-18 fix: improve operator connection handling
    - Use ToSocketAddrs for rover address to support hostname resolution
    - Only warn once on operator connection timeout (prevents log spam)
    [lib.rs, main.rs]
2025-12-18 fix(camera): correct GStreamer CSI pipeline for BGRx format
    nvvidconv outputs BGRx, not RGB directly. Add videoconvert stage
    to properly convert to RGB for the appsink.
    [lib.rs]
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2025-12-19 feat(bvrd): integrate WebSocket teleop server
    - Add --ws-port flag for browser operator connections (default 4850)
    - Spawn WsServer alongside existing UDP teleop
    - Improve permission error message with helpful alternatives
    When log directory creation fails, now shows:
    cargo run --bin bvrd -- --sim --log-dir ./logs --recording-dir ./sessions
    [main.rs]
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2025-12-19 chore: remove legacy Bevy-based operator app
    Replaced by web-based operator in depot/operator/ which provides:
    - Browser-based access from any platform
    - 360° video streaming via WebSocket
    - WebXR support for Vision Pro
    - Packaged with depot infrastructure
    [main.rs]
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2025-12-20 feat(firmware): integrate discovery and update motor config
    - Add discovery client initialization with --no-discovery flag
    - Update default endpoints from depot.local to depot (Tailscale)
    - Fix pole pairs: 16 (32 poles / 2)
    - Fix wheel diameter: 160mm
    - Switch motor control from RPM to duty cycle
    - Add smoothing alpha adjustment (0.5 for faster response)
    [main.rs]
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2025-12-21 fix(cli): add boost field to twist command
    Update CLI drive command to include boost field in Twist struct.
    [main.rs]
2025-12-21 fix(can): check all VESCs for battery voltage reading
    Iterate through all 4 VESCs to find a valid battery voltage,
    rather than just checking front-left and front-right. This
    handles cases where some VESCs aren't sending STATUS5 messages.
    [vesc.rs]
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2025-12-22 feat: Add RL training environment and simulation capabilities (#1)
    This commit introduces a new reinforcement learning (RL) environment for BVR navigation. It includes:
    - **RL Crate:** A new `rl` crate providing the core RL environment interface, observations, actions, rewards, and spaces.
    - **Simulation Enhancements:**
    - **Physics:** Added collision detection and rollback to the `Physics` module.
    - **LiDAR:** Implemented synthetic LiDAR simulation with ray-casting and configuration options.
    - **World:** Enhanced the `World` module with obstacle generation (boxes, walls) and ray-casting capabilities.
    - **Training Binary:** A new `train` binary is added to run RL experiments, inc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
    [lib.rs, main.rs]
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2025-12-24 fix(bvrd): remove unnecessary ref and mut in autonomous mode
    Fix compilation errors from PR #2:
    - Remove explicit `ref` binding in pattern match (implicitly borrowed)
    - Remove unused `mut` from autonomous_goal variable
    [main.rs]
2025-12-24 fix(control): add missing boost field in test Twist initializers
    Add boost: false to Twist struct initializers in control crate tests
    to match the updated Twist type definition.
    [lib.rs]
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2025-12-28 fix(mcu): get RP2350 LED firmware working on Pico 2 W
    Key fixes for RP2350/Pico 2 W compatibility:
    - Add boot2-w25q080 feature for flash bootloader
    - Add critical-section-impl and binary-info features
    - Use proper memory.x with boot block sections (.start_block, .end_block)
    - Add --nmagic linker arg via build.rs
    - Use picotool for flashing (elf2uf2-rs uses wrong family ID)
    Also simplified firmware to focus on LED control, stubbed out CAN
    until MCP2515 hardware is connected. Comprehensive troubleshooting
    docs added to README.
    [lib.rs, main.rs]
2025-12-28 feat(networking): replace LTE with Ubiquiti mesh architecture
    Switch from LTE-based connectivity to 5 GHz Ubiquiti mesh network:
    - Add mesh-first strategy with data-driven repeater deployment
    - Add Proxicast 7-in-1 combo antenna for rovers
    - Add Rocket 5AC Prism + omni antenna for depot base station
    - Add MeshMetrics struct to metrics crate for coverage analysis
    - Add patron WiFi option with VLAN isolation
    - Update depot hardware: UDM SE gateway, PoE budget, port allocation
    - Update RTK delivery to use mesh instead of LTE
    Benefits: 5-50ms latency (vs 100-250ms LTE), no recurring data costs,
    self-contained network with optional community WiFi.
    [lib.rs]
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2025-12-29 feat(mcu): add ESP32-S3 firmware for Heltec LoRa 32 V3
    Features:
    - OLED display with animated UI and splash screen
    - Serial command interface (led, state, help)
    - WS2811 LED driver (requires 3.3V-5V level shifter)
    - Proper bootloader for ESP32-S3 v0.2 chip compatibility
    Includes comprehensive documentation on:
    - Linker script requirements (-Tlinkall.x)
    - Bootloader compatibility (ESP-IDF v5.1 for older chips)
    - OLED initialization (Vext power, reset sequence)
    - WS2811 level shifting requirements
    [partitions.csv]
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2025-12-30 feat(mcu): add status LED bar and RMT-based addressable LED driver
    - Add status-bar feature with 5 GPIO LEDs (19, 20, 26, 48, 47)
    - Add status-led feature for single onboard LED patterns
    - Rewrite ws2812.rs to use RMT peripheral for precise timing
    - Support WS2811 (400kHz) and SK68xx/WS2812 (800kHz) protocols
    - Add RGB/GRB/BGR color order options
    - Implement BarState: Idle, Running, Error, Warning, Startup, AllOn
    - Add serial commands: state, on, off, blink
    - Battery-saving heartbeat: 33ms flash every 2 seconds
    [main.rs]
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2025-12-30 refactor(mcu): apply clippy suggestions
    - Use is_multiple_of() instead of manual modulo check
    - Apply other clippy auto-fixes
    [main.rs]
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2025-12-30 feat(mcu): implement SLCAN protocol for CAN-over-USB
    - Add can_protocol.rs: CAN message ID scheme for attachments
    - ID range 0x200-0x20F for attachment slot 0
    - Heartbeat, Identity, Command, Ack, Sensor, Config, Error messages
    - Command codes for LED control, state, enable/disable
    - Add slcan.rs: Serial Line CAN protocol parser
    - Standard and extended frame support
    - Open/Close channel, Version, Serial commands
    - Integrate SLCAN into main loop
    - Auto-detect SLCAN vs text commands
    - Process incoming CAN frames and send responses
    - Periodic heartbeat (~1Hz) when channel is open
    - Full-stack ready: bvrd can discover, monitor, and control attachment
    [main.rs]
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2025-12-31 feat(cli): add unified muni CLI with GPS monitor and configuration
    - Refactor CLI to use 'muni' with 'rover' and 'gps' subcommands
    - Add gps.rs: real-time TUI monitor for GNSS receivers
    - Auto-detects rover (NMEA) vs base station (RTCM/UBX) mode
    - Shows satellite signal bars per constellation
    - Base station: survey-in progress, RTCM message stats
    - Rover: position, fix quality, HDOP, satellite count
    - Add gps configure-base: configure ZED-F9P as RTK base station
    - Supports fixed position or survey-in mode
    - Enables RTCM3 output, disables NMEA
    - Saves configuration to flash (persists across power cycles)
    - Add gps configure-rover: configure ZED-F9P as RTK rover
    - Enables NMEA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
    [gps.rs, main.rs]
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2025-12-31 feat(depot): add gps-status microservice
    Rust service that queries the ZED-F9P GPS module via serial and exposes
    status information:
    - WebSocket endpoint (/ws) for live GPS status updates
    - HTTP endpoint (/status) for polling
    - Health check endpoint (/health)
    Reports fix quality, satellites, position, survey-in progress, RTCM
    messages, and connected client count. Runs with the 'rtk' Docker profile.
    [main.rs]
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2025-12-31 fix(depot): resolve lint warnings in console and gps-status
    - Fix useGpsStatus hook self-reference issue using ref pattern
    - Remove unused 'error' import from gps-status
    [main.rs]
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2026-01-05 feat(cad): add parametric CAD system with motor mount for BVR1 (#9)
    * feat(cad): add parametric CAD system with motor mount for BVR1
    Implement a Rust-based CAD system using manifold-rs for CSG operations:
    - Part abstraction with primitives (cube, cylinder, sphere)
    - Boolean ops (union, difference, intersection)
    - Transforms (translate, rotate, scale)
    - STL export for 3D printing and manufacturing
    Add motor mount design for 8" hub motors:
    - L-bracket design for 2020 extrusion mounting
    - 15mm axle hole, 4x M6 on 70mm bolt circle
    - 6mm aluminum plate thickness
    - Separate flat plate and tab exports for laser cutting
    * fix(cad): correct tab hole positions along Y axis
    Holes were positioned a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
    [motor_mount_8in.stl, motor_mount_plate_8in.stl, motor_mount_tab_8in.stl]
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2026-01-07 fix(firmware): add missing mesh field to MetricsSnapshot initializers
    Use struct update syntax with Default to handle new mesh field.
    [lib.rs, main.rs]
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2026-01-11 feat(bvrd): integrate dispatch client for mission execution
    - Add dispatch client initialization with configurable endpoint
    - Handle TaskAssigned events to receive waypoints from depot
    - Handle TaskCancelled events to abort current mission
    - Wire autonomous mode to use dispatched waypoints (priority over static goal)
    - Report progress as waypoints are reached
    - Report task completion/failure back to dispatch service
    - Make DispatchClient cloneable for async task spawning
    - Add --no-dispatch and --dispatch-endpoint CLI args
    - Add [dispatch] section to config file support
    [lib.rs, main.rs]
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2026-01-15 feat(web): update deposit to $999 and add floating header
    - Update deposit amount from $99 to $999 across homepage and products page
    - Add floating header with glassmorphism effect
    - Sharp corners, centered layout
    - Logo + 'Municipal Robotics' wordmark + navigation
    - Fixed hover states to prevent orange background bleeding
    - Improve final CTA section
    - Add FOMO elements: early access, delivery slots, production timeline
    - Convert learn more links to button-style elements
    - Prominent risk reversal messaging
    - Redesign footer from first principles
    - Clean 3-column layout (Resources, Contact, Social)
    - Remove newsletter form (was causing layout issues)
    - Professional copyright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
    [lib.rs]
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2026-01-15 feat(cad): implement 3-panel clam shell design for SendCutSend
    Add 2-panel clam shell design with Wall Wrap + Top Lid + Skid Plate:
    - WallWrap: Front + sides + rear as single bent piece (1931mm × 200mm)
    - Blower nozzle slot and LED channel on front
    - Louver vents (stadium slots) on rear for positive pressure airflow
    - 3 bend lines for 90° bends at corners
    - TopLid: Removable top panel (420mm × 540mm)
    - Sensor mast hole (150mm) for LiDAR + camera
    - E-stop hole (30mm) and GPS grommet (12mm)
    - M5 mounting holes around perimeter
    - SkidPlate: Bottom protection panel (420mm × 540mm)
    - 6mm drain holes at corners with grommet provision
    - M5 mounting holes for frame attachment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
    [shell_front.stl, shell_rear.stl, shell_side_left.stl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]
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2026-01-16 feat(cad): add multi-material realistic assembly export
    - Add Scene/SceneNode structs for multi-part assemblies with materials
    - Implement export_scene_glb() for multi-mesh GLB with PBR materials
    - Add generate_scene() to BVR1Assembly with proper material assignments
    - Fix shell wall height to match frame vertical posts (180mm)
    - Position shell at frame bottom (gc=50mm) aligned with frame top
    - Add knuckle hinge tabs, gas strut mounts, quarter-turn latches to shell
    - Update DXF export with bend line support
    Materials: aluminum_6061 (frame), aluminum_powder_orange (shell),
    rubber_tire (wheels), hdpe_black (tray/panel), heatsink_aluminum (VESCs)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
    [bvr0_assembly.stl, bvr1_assembly.stl, bvr1_frame.stl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]
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2026-01-18 feat(lidar): replace RPLidar A1 with Livox Mid360 driver
    Replace the 2D serial-based RPLidar A1 driver with a 3D UDP-based
    Livox Mid360 driver. The Mid360 provides 360° × 59° FOV point clouds
    at up to 200k points/second.
    - Rewrite lidar crate for Livox SDK2 UDP protocol
    - Add 3D PointCloud type with Point3D (x, y, z, reflectivity, tag)
    - Support Cartesian 32-bit, 16-bit, and Spherical point formats
    - Add optional IMU data streaming from Mid360
    - Update costmap/slam to project 3D points to ground plane
    - Update recording to log 3D point clouds to Rerun
    - Update bvrd integration for async UDP instead of blocking serial
    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
    [lib.rs, main.rs]
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2026-01-18 chore(cad): regenerate exports for Friendly Industrial shell
    Regenerated all CAD exports after shell redesign:
    - STL: Updated assembly and shell parts
    - GLTF: Updated 3D models with sensor dome
    - USD: Updated Isaac Sim robot model
    - DXF: Updated flat patterns with front rake bend line
    New export: sensor_dome (3D printed component)
    [bvr1_assembly.stl, sensor_dome.stl, shell_wall_wrap.dxf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]
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2026-01-20 feat(teleop): add WebRTC DataChannel for low-latency commands
    Replace TCP/WebSocket teleop with WebRTC DataChannel for UDP-like
    unreliable, unordered delivery. This eliminates head-of-line blocking
    and retransmission delays that cause jerky teleop control.
    - Add webrtc crate to workspace dependencies
    - Create rtc.rs with WebRTC signaling and DataChannel server
    - Add video streaming over WebRTC DataChannel
    - Optimize command processing with "latest Twist wins" pattern
    - Wire up RTC server in bvrd with --rtc-port argument
    [lib.rs, main.rs]
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2026-01-20 feat(hal): add hardware e-stop GPIO support with software debouncing
    Implements P0-2 from the refactor plan. Adds EStopInput abstraction for
    reading hardware e-stop button state via GPIO on Linux/Jetson platforms.
    - Add EStopConfig with gpio_chip, gpio_line, active_low, debounce_ms options
    - Implement software debouncing with configurable threshold
    - Support both active-low (NC to ground) and active-high configurations
    - Add latch semantics requiring explicit reset after e-stop activation
    - Feature-gate GPIO implementation behind 'gpio' feature (Linux only)
    - Add comprehensive tests for debouncing and active-low/high logic
    - Add [estop] config section to bvr.toml with sensible defaults
    Co-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
    [lib.rs, main.rs]
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2026-01-20 fix(dispatch): add task recovery on rover disconnect
    CRITICAL FIX: Tasks were becoming orphaned when rovers crashed or
    disconnected - they remained in assigned/active status forever.
    On rover disconnect:
    - Query for any assigned/active tasks belonging to that rover
    - Mark them as failed with error "Rover disconnected"
    - Broadcast task updates to console clients
    Background cleanup loop (runs every 60s):
    - Finds tasks stuck in assigned/active status for disconnected rovers
    - Fails tasks older than TASK_TIMEOUT_MINUTES (default: 5 minutes)
    - Configurable via TASK_TIMEOUT_MINUTES environment variable
    This ensures:
    - No tasks are left in limbo when rovers crash
    - Console UI accurately reflects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
    [main.rs]
2026-01-20 feat(gps-status): add satellite details and history tracking
    - Parse GSV sentences for individual satellite info (PRN, constellation,
    elevation, azimuth, SNR)
    - Parse GSA sentences for VDOP/PDOP and which satellites are used in fix
    - Track constellation types (GPS, GLONASS, Galileo, BeiDou, QZSS)
    - Add history buffer (60 points) for frontend charts
    - Include satellite "used" status from GSA cross-reference
    [main.rs]
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2026-01-20 feat(control-loop): create modular control loop crate structure
    Begin P1-3 refactor to extract the 800+ line control loop from main.rs
    into a modular crate. This commit establishes the foundation:
    Crate structure:
    - lib.rs: Config, stats, timing, error types
    - command_processor.rs: Drain/route teleop commands ("latest Twist wins")
    - telemetry_builder.rs: Collect telemetry from all subsystems
    Key types:
    - ControlLoopConfig: Period, watchdog timeout, limits
    - ControlLoopStats: CAN error tracking with backoff
    - CommandProcessor: Non-blocking command channel drain
    - ProcessedCommands: Categorized command results
    - TelemetryBuilder: Construct Telemetry from subsystem data
    Tests: 10 unit tests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
    [lib.rs, telemetry_builder.rs]
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2026-01-20 fix(gps-status): deduplicate satellites by PRN and constellation
    - Move satellite update to GGA handler (once per NMEA cycle)
    - Use HashMap to deduplicate by (constellation, PRN) key
    - Keep entry with highest SNR when duplicates exist
    - Add Hash derive to Constellation enum
    Fixes issue where satellites were repeated in the list due to
    multiple GSV messages from same constellation (e.g., L1/L5 signals).
    [main.rs]
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2026-01-20 fix(console): fix dashboard sidebar visibility and remove redundant HUD
    - Override map z-50 with !z-0 to prevent covering sidebar
    - Use absolute inset-0 for map positioning within content area
    - Remove redundant overlay cards (Base Station, Fleet, Quick Actions)
    since this info is now in the sidebar
    [bvr1_assembly.stl]
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2026-01-20 feat(cli): add deploy subcommands for depot and rovers
    Adds `muni deploy` command with two subcommands:
    - `muni deploy depot` - rsync + docker compose build/up
    - `muni deploy rover <hostname>` - cross-compile + scp + restart
    Replaces the old deploy.sh bash script with native Rust implementation.
    [main.rs]
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2026-01-20 feat(teleop): add connecting indicator and populate health status
    Console:
    - Add `connecting` state to show spinner while WebRTC connects
    - Show "Connecting to [rover]..." overlay during connection
    Firmware:
    - Populate SubsystemHealth from actual component states:
    - CAN: battery voltage > 0 (drivetrain communication)
    - Recording: enabled and recorder active
    - GPS: valid fix with coordinates
    - Camera: started successfully
    - Dispatch/Discovery: enabled in config
    - LiDAR: enabled in config
    - SLAM: processor initialized
    [main.rs]
2026-01-20 fix(teleop): improve WebRTC reliability and camera handling
    - Make command channel reliable (ordered: true) to prevent SetMode
    packets from being dropped - fixes Enable button not working
    - Set up on_message handler synchronously to avoid missing early
    messages from browser
    - Add 10s timeout around camera detection to prevent bvrd hanging
    when GStreamer init blocks (common on Jetson with NVIDIA plugins)
    - Improve video frame handling with stale frame detection and
    proper channel readyState checks
    - Clean up verbose debug logging, keep important events (mode
    changes, E-Stop, first frames, errors)
    [lib.rs, main.rs]
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
